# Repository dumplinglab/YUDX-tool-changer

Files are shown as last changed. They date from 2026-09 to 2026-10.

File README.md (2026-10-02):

# YUDX Tool Changer

An open-source automatic tool-changing system for 3D printers that enables **1-second tool changes with almost zero waste**.

## ✨ Key Features

- **~1 second tool change** — near-instant switching between tool heads, and dramatically reducing purge/waste material compared to traditional multi-material setups.
- **Preheatable tool heads** — each tool head has its own independent heater and thermistor, so it can be pre-heated in advance while parked.
- **Simple, reliable mechanism** — the tool-docking mechanism is based on a one-way bearing design, which keeps the system mechanically simple while remaining stable and reliable.

## 🖨️ Compatibility

Currently designed as a conversion for:
- **Voron 2.4**
- **Voron Trident**

Support for additional printer platforms may be added in the future.

## 👤 Author

It's just me — **dumpling**. No company, no team, just one person working on this.

I'm a student in Shanghai, just starting my third year of university, and I've loved DIY 3D printers since middle school, designing and building my own machines for years.

Since this is a one-person project that I work on in my spare time, updates may come slowly — thanks for your patience and interest!

## 🧵 Firmware & G-code

The G-code provided in this repository is generated for **RepRapFirmware (RRF)**.

If you are running **Klipper**, you will need to write your own tool-change macros/G-code for now. If you do write a working Klipper configuration, contributions are very welcome — please consider opening a pull request so other Klipper users can benefit.

## 💬 Community

Join the Discord: [https://discord.gg/huHw8kzNXp](https://discord.gg/huHw8kzNXp)

## 🔧 Installation

See [Assembly Instructions](<./YUDX Assembly Instruction.pdf>) for the full build and installation guide.

## 📦 Bill of Materials

See [BOM.xlsx](<./"YUDX"BOM.xlsx>) for the complete parts list.

## 📄 License

See the [LICENSE](./LICENSE) file for details.

## 📖 Project Background

I've been developing an automatic tool-changing 3D printer since 2024. Initially, I experimented with a design similar to the Prusa XL's tool-changing approach.

Everything changed in April 2025, when I saw the reveal video for Bondtech's INDX system. I was blown away, and it pushed me to take the design in a new direction. Many thanks to Bondtech for the inspiration.

I explored a number of different mechanical designs. Then, one night in May 2025, the idea for the current one-way bearing mechanism came to me in a dream — a solution that turned out to be simple, stable, and reliable. Since building and machining the first prototype, the design has gone through continuous refinement, and reliability is now solid.

## 🙏 Acknowledgments

- **Bondtech** — for the INDX system, which was a huge inspiration for the tool-changing approach used in this project.
- **whyme12** — for helping add screws and nuts, and for completing the BOM spreadsheet.
- **Voron Design** — the open-source Voron project that this system is built on top of.
- **RepRapFirmware (RRF)** — the open-source firmware this project's G-code is developed for.

## 🤝 Contributing

Contributions are welcome, especially:
- Klipper-compatible tool-change G-code / macros
- Bug reports and reliability improvements
- Documentation improvements

Feel free to open an issue or pull request.

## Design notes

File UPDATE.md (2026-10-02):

# \## 🔴 Important Changes

# 1\. \*\*Corrected the Maxwell locating point structure\*\*

# For the original structure: under high-flow conditions, the locating point would slip, directly affecting print accuracy. It has now been adjusted so that \*\*the greater the extrusion amount, the tighter the clamping\*\*. Even if the extruder skips steps, the toolhead will not slip, greatly improving positioning reliability.

# 2\. \*\*Replaced square nuts with heat-set inserts\*\*

# The original solution used square nuts, which tended to loosen after long-term use; they have been changed to heat-set inserts to improve the long-term stability.

# 

# \## 🟡 Minor Optimizations and Detail Adjustments

# 1\. Shifted the push latch switch upward by 3 mm to prevent interference/collision with screws when removing or installing the toolhead.

# 2\. Adjusted the silicone plug installation position to correct the off-center issue and ensure it is centered.

# 3\. Added a lightweight structural design to CNC machined parts to reduce weight while maintaining strength.

# 4\. Changed multiple self-tapping screw mounting positions to heat-set inserts to improve connection durability.

# 5\. Fully added the screw standard parts in the assembly file.

# 6\. Fixed several minor design flaws.

\## 🟢 Pending Updates

1\. The BOM and assembly instructions have not been updated yet; I will update them later when I have time.

2\. The new version has overridden the previous whyme12 version's design of "using a Hall switch to detect whether the toolhead change is successful." Later, I plan to create a new branch to add this design back.

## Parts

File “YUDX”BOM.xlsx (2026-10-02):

 | Info: 1. The finished YUDX extruder kit may be released in the coming months. You may wait for its launch. 2. Amazon links were found by Claude Code. Links may be incorrect, please feedback any errors to me. 3. discord:https://discord.gg/huHw8kzNXp 4. https://github.com/dumplinglab/YUDX-tool-changer
number | Notes | Part Name (corresponds to STEP file) | Qty | Type | Amazon Product | Price | Amazon Link
1 | VORON existing part | MGN12H_block | 1 | Standard Part | MGN12H 300mm Premium Linear Guide Rail 2 Pcs MGN12 Linear Slide 8mm for 3D Printer CNC (2 Pcs/Pack) | $26.92 | https://www.amazon.com/dp/B09ZPHPB5F
2 | VORON existing part | MGN12 | 1 | Standard Part | MGN12H 300mm Premium Linear Guide Rail 2 Pcs MGN12 Linear Slide 8mm for 3D Printer CNC (2 Pcs/Pack) | $26.92 | https://www.amazon.com/dp/B09ZPHPB5F
3 | VORON existing part | Aluminum profiles | 1 | Standard Part |  | $0
4 | Extruder kit | outer_shell_of_extruder | 1 | 3D Printed Part |  | $0
5 | Extruder kit | gear_container_plastic_part | 2 | 3D Printed Part |  | $0
6 | Extruder kit | rack_below_part | 1 | 3D Printed Part |  | $0
7 | Extruder kit | double_layer_gear | 2 | Custom Gear |  | $35
8 | Extruder kit | extrude_gear | 2 | Custom Gear |  | $19.40
9 | Extruder kit | 0.5m10gear | 2 | Custom Gear |  | $32
10 | Extruder kit | gear_container_metal_part | 2 | Custom CNC Part |  | $18.8
11 | Extruder kit | axle_for_extrude_gear | 2 | Custom CNC Part |  | $23
12 | Extruder kit | gear_container_metal_part_mirror | 2 | Custom CNC Part |  | $18.8
13 | Extruder kit | extruder_bottom_metal_part | 1 | Custom CNC Part |  | $9.9
14 | Extruder kit | extruder_top_metal_part | 1 | Custom CNC Part |  | $9.9
15 | Extruder kit | extruder_top_metal_part_mirror | 1 | Custom CNC Part |  | $9.9
16 | Extruder kit | line_cut_rack | 1 | Custom Wire-cut Part |  | $24
17 | Extruder kit | 36_stepper_motor | 1 | Custom Motor |  | $12.82
18 | Extruder kit | screwM3_14 | 2 | Screw |  | $0.50
19 | Extruder kit | one_way_bearing | 2 | Custom Bearing |  | $7.47
20 | Extruder kit | extrude_wheel | 2 | Standard Part | Precise Double Drived Gear Extruder Gear Set for HGX-LITE-extruder Hardened Steel Extruder Driver Gear Set | $10.42 | https://www.amazon.com/gp/product/B0FD3XDJMK
21 | Extruder kit | needle_bearing | 2 | Standard Part | Precise Double Drived Gear Extruder Gear Set for HGX-LITE-extruder Hardened Steel Extruder Driver Gear Set | $0 | https://www.amazon.com/gp/product/B0FD3XDJMK
22 | Extruder kit | 4mm_flange_bearing | 6 | Standard Part | M METERXITY 20pcs MF63ZZ Flange Ball Bearings, 3mm x 6mm x 2.5mm, Dual Metal Seal Chrome Steel (GCr15) | $7.10 | https://www.amazon.com/dp/B0F4XS52R6
23 | Extruder kit | 3mm_flange_bearing | 4 | Standard Part | M METERXITY 20pcs MF63ZZ Flange Ball Bearings, 3mm x 6mm x 2.5mm, Dual Metal Seal Chrome Steel (GCr15) | $7.10 | https://www.amazon.com/dp/B0F4XS52R6
24 | Extruder kit | 4mm_axle | 2 | Standard Part |  | $0.5
25 | Extruder kit | cylinder_pin1.5_5 | 6 | Standard Part | Swpeet 300Pcs 15 Sizes M1 M1.5 304 Stainless Steel Dowel Pin Assortment Kit | $6.72 | https://www.amazon.com/dp/B0G8ZXBGN1
26 | Extruder kit | 4mm_flange_bearing_8mm | 2 | Standard Part | F693ZZ Flange Ball Bearing, ID 3mm x OD 8mm x Width 4mm, Double Metal Shield Deep Groove, Pre-lubricated (GCr15) 10 Pcs | $5.98 | https://www.amazon.com/dp/B0CRLH1WT1
27 | Extruder kit | spring_0.8x7x30 | 1 | Standard Part |  | $2
28 | Extruder kit | 4mm_ball | 32 | Standard Part | 50pcs 4mm 304 Stainless Steel Bearing Balls, 0.15in G200 Precision 28HRC | $4.11 | https://www.amazon.com/dp/B0F2S945ZC
29 | Extruder kit | square_nut | 2 | Standard Part | M3nS Prusa Thin M3 Square Nuts - A2 Stainless Steel DIN 562 (Qty 25) | $5.95 | https://www.amazon.com/dp/B0BD2N9KTV
30 | Extruder kit | mini_door_lock_switch | 16 | Standard Part | 5PCS Door Lock Switch PR-03 Key Switches | $24.68 | https://www.amazon.com/5PCS-Door-Switch-PR-03-Switches/dp/B0H9KGYYP8
31 | Extruder kit | 4.5mm_silicon_sleeve | 7 | Standard Part |  | $5.2
32 |  | Tool_head_front_part | 1 | 3D Printed Part |  | $0
33 |  | Tool_head_back_part | 1 | 3D Printed Part |  | $0
34 |  | voron_connecting_part | 1 | 3D Printed Part |  | $0
35 |  | throat_cooling_fan_seat | 1 | 3D Printed Part |  | $0
36 |  | model_cooling_fan_seat | 1 | 3D Printed Part |  | $0
37 |  | front_cover | 1 | 3D Printed Part |  | $0
38 |  | back_cover | 1 | 3D Printed Part |  | $0
39 |  | tool_head_seat | 7 | 3D Printed Part |  | $0
40 |  | nozzle_cleaning_part | 7 | 3D Printed Part |  | $0
41 |  | air_guide | 7 | 3D Printed Part |  | $0
42 |  | magnet_5-15-3 | 32 | Standard Part | BEST CHOICE Neodymium Magnets 15x3mm, 50pcs Fridge Magnets Rare Earth Magnets for Crafts | $11.21 | https://www.amazon.com/Neodymium-Rectangular-Industrial-Applications-15mmx5mmx4mm/dp/B0GKPBWNSF
43 |  | Bambu_Hotend | 8 | Standard Part | Genuine Bambu Lab Hotend with Nozzle for P1S P1P X1C X1 Carbon 3D Printer .4mm Hardened Steel | $160 | https://www.amazon.com/Genuine-Printer-4mm-Hardened-Steel/dp/B0D2WG7CXQ
44 |  | 2510fan | 1 | Standard Part | 2510 Axial Fan DC 24V, 25x25x10mm Dual Ball Bearing Low Noise Brushless Cooling Fan for 3D Printer Extruder Hotend (2 Pcs) | $11.20 | https://www.amazon.com/dp/B0FR99DQWY
45 |  | 5020fan | 1 | Standard Part | Cooling Case PC Fan 50x50x20mm DC 24V 0.15A 5020 Brushless 2-Pin XH2.54 5500RPM | $4.68 | https://www.amazon.com/dp/B0CWCXGYG1
46 |  | bed_switch | 1 | Standard Part | 20PCS Micro Limit Switch NO+NC Hinge Straight Lever 3PIN 125V 1A Mouse Micro Touch Button Momentary Switch Black | $4.89 | https://www.amazon.com/DAOKAI-Switch-Straight-Button-Momentary/dp/B09WVMRD5V
47 |  | 3010fan | 8 | Standard Part | 3010 Axial Fan DC 24V, 30x30x10mm Hydraulic Bearing Low Noise Silent Brushless Cooling Fan for 3D Printer Extruder Hotend (2 Pcs) | $10.46 | https://www.amazon.com/dp/B0FRFNZFDP

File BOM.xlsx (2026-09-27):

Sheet: BOM
 | Info: 1. The finished YUDX extruder kit may be released in the coming months. You may wait for its launch. 2. Amazon links were found by Claude Code. Links may be incorrect, please feedback any errors to me. 3. discord:https://discord.gg/vE4ExaVR3 4. https://github.com/dumplinglab/YUDX-tool-changer
number | Part group | Part Name (corresponds to STEP file) | Qty | Type | Details | Notes
1 | VORON existing part | MGN12H_block | 1 | Standard Part | MGN12H 300mm Premium Linear Guide Rail 2 Pcs MGN12 Linear Slide 8mm for 3D Printer CNC (2 Pcs/Pack)
2 | VORON existing part | MGN12 | 1 | Standard Part | MGN12H 300mm Premium Linear Guide Rail 2 Pcs MGN12 Linear Slide 8mm for 3D Printer CNC (2 Pcs/Pack)
3 | VORON existing part | Aluminum profiles | 1 | Standard Part
4 | Printer specific part | voron_connecting_part | 1 | 3D Printed Part |  | Add mounting option for EBB36?
5 | Printer specific part | M3x8mm ISO4762 | 4 | Standard Part | Screws to mount to MGN12 block
6 | Extruder | outer_shell_of_extruder | 1 | 3D Printed Part
7 | Extruder | double_layer_gear | 2 | Custom Gear
8 | Extruder | extrude_gear | 2 | Custom Gear
9 | Extruder | extrude_wheel | 2 | HGX-Lite | All included in a single HGX-Lite gear kit
10 | Extruder | needle_bearing | 2 | HGX-Lite | All included in a single HGX-Lite gear kit
11 | Extruder | one_way_bearing | 2 | Standard Part | HF0306
12 | Extruder | gear_container_metal_part | 2 | CNC
13 | Extruder | axle_for_extrude_gear | 2 | Custom part? | Diameter: 3mm, length: 24mm, 8mm ground flat on one side (1/4 D-Shaft) | change to D-shaft?
14 | Extruder | 0.5m10gear | 2 | Standard Part? | M0.5, 10 teeth, 3mm D-shaft | change to 12 teeth for more strength?
15 | Extruder | gear_container_plastic_part | 2 | 3D Printed Part
16 | Extruder | gear_container_metal_part_mirror | 2 | CNC
17 | Extruder | 4mm_flange_bearing | 6 | Standard Part | MF74ZZ flange bearing 4mmx7mmx2.5mm
18 | Extruder | 3mm_flange_bearing | 4 | Standard Part | MF63ZZ flange bearing 3mmx6mmx2.5mm
19 | Extruder | 4mm_axle | 2 | Standard Part | length 32mm
20 | Extruder | line_cut_rack | 1 | Custom Wire-cut Part | M0.5 gears require wire cutting
21 | Extruder | rack_below_part | 1 | CNC
22 | Extruder | extruder_bottom_metal_part | 1 | CNC
23 | Extruder | 36_stepper_motor | 1 | Standard part? | possibly fitting motor: Flashforge AD5X extruder motor
24 | Extruder | cylinder_pin1.5_5 | 6 | Standard Part | Diameter: 1.5mm, Length: 4mm
25 | Extruder | 4mm_flange_bearing_8mm | 2 | Standard Part | MF84ZZ flange bearing 4mmx8mmx3mm
26 | Extruder | extruder_top_metal_part_mirror | 1 | CNC
27 | Extruder | extruder_top_metal_part | 1 | CNC
28 | Extruder | throat_cooling_fan_seat | 1 | 3D Printed Part
29 | Extruder | 2510fan | 1 | Standard Part
30 | Extruder | model_cooling_fan_seat | 1 | 3D Printed Part
31 | Extruder | spring_0.8x7x30mm | 1 | Standard Part
32 | Extruder | 5020fan | 1 | Standard Part
33 | Extruder | bed_switch | 1 | Standard Part | for example: Omron D2F-01
34 | Extruder | M2x8mm ISO4762 | 2 | Standard Part | M2x8mm ISO4762
35 | Extruder | M3x10mm ISO7380-1 | 4 | Standard Part | Screws to mount model_cooling_fan_seat
36 | Extruder | front_cover | 1 | 3D Printed Part
37 | Extruder | M3x8mm ISO7380-1 | 2 | Standard Part | Screws to mount front_cover
38 | Extruder | back_cover | 1 | 3D Printed Part
39 | Extruder | M3x30mm ISO7380-1 | 8 | Standard Part | Screws to mount extruder_top_metal_part to extruder_bottom_metal_part
40 | Extruder | M3x8mm ISO10642 | 2 | Standard Part | Screws to mount stepper motor
41 | Extruder | M3x10mm ISO4762 | 4 | Standard Part | Screws to mount extruder_bottom_metal_part to voron_connecting_part
42 | Extruder | M3x8mm ISO10642 | 4 | Standard Part | Screws to mount gear_container_metal_part
43 | Extruder | M3x5mm ISO7380-1 | 2 | Standard Part | Screws to mount gear_container_plastic_part to gear_container_metal_part
44 | Extruder | M3x12mm ISO7380-1 | 2 | Standard Part | Screws for Spring
45 | Extruder | M3x14mm ISO7380-1 | 4 | Standard Part | Screws to mount 2510fan | Walls could be too thin around heat inserts, needs to be tested
46 | Extruder | M3x12mm ISO7380-1 | 3 | Standard Part | Screws to mount throat_cooling_fan_seat
47 | Extruder | A1104_hall_effect_sensor | 1 | Standard Part | (optional) Hall effect sensor A1104LUA-T (not SMD variant) to detect tool change fails
48 | Extruder & Toolhead | magnet_5-15-3 | 4 + N*4 | Standard Part |  | Pocket size in Step maybe to small? Only 14.5x4.5mm
49 | Toolhead | Tool_head_front_part | N | 3D Printed Part |  | Pocket size in Step maybe to small? Only 14.5x4.5mm
50 | Toolhead | Bambu_Hotend | N | Standard Part |  | Create second Tool_head_front_part to support Snapmaker U1 hotends
51 | Toolhead | 4mm_ball | N*4 | Standard Part | 4mm ball bearing ball
52 | Toolhead | Tool_head_back_part | N | 3D Printed Part |  | Do the latches work when 3d printed and not break off?
53 | Toolhead | square_nut | N*2 | Standard Part
54 | Toolhead | M3x14mm ISO4762 | N*2 | Standard Part | Screws to mount Bambu_Hotend
55 | Toolhead | M3x6mm ISO7380-1 | N*4 | Standard Part | Screws to mount Tool_head_back_part to Tool_head_front_part
56 | Toolhead | Magnet_4x2mm | N | Standard Part | Diameter 4mm, height 2mm | To be able to detect toolchange success using hall effect sensor
57 | Dock | tool_head_seat | N | 3D Printed Part |  | Maybe add additional screws from front?
58 | Dock | mini_door_lock_switch | N*2 | Standard Part
59 | Dock | nozzle_cleaning_part | N | 3D Printed Part
60 | Dock | 3010fan | N | Standard Part
61 | Dock | air_guide | N | 3D Printed Part
62 | Dock | 4.5mm_silicon_sleeve | N | ??? |  | where to get this part from?
63 | Dock | M3x12mm ISO4762 | N*4 | Standard Part | Screws to mount nozzle_cleaning_part
64 | Dock | M3x20mm ISO4762 | N*4 | Standard Part | Screws to mount 3010fan and air_guide
65 | Dock | M3x8mm ISO4762 | N*2 | Standard Part | Screws to mount tool_head_seat to aluminium extrusion
66 | Dock | T-nut | N*2 | Standard Part | T-nut to mount tool_head_seat to aluminium extrusion
67 | Overall | Heat set inserts | 31+N*8 | Standard Part | Heat set inserts M3x5x4mm (Voron style)

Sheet: Screw types
Type | Quantity
M3x8mm ISO4762 | 4+N*2
M3x10mm ISO4762 | 4
M3x12mm ISO4762 | N*4
M3x14mm ISO4762 | N*2
M3x20mm ISO4762 | N*4
M3x8mm ISO10642 | 6
M3x5mm ISO7380-1 | 2
M3x6mm ISO7380-1 | N*4
M3x8mm ISO7380-1 | 2
M3x10mm ISO7380-1 | 4
M3x12mm ISO7380-1 | 5
M3x14mm ISO7380-1 | 4
M3x30mm ISO7380-1 | 8

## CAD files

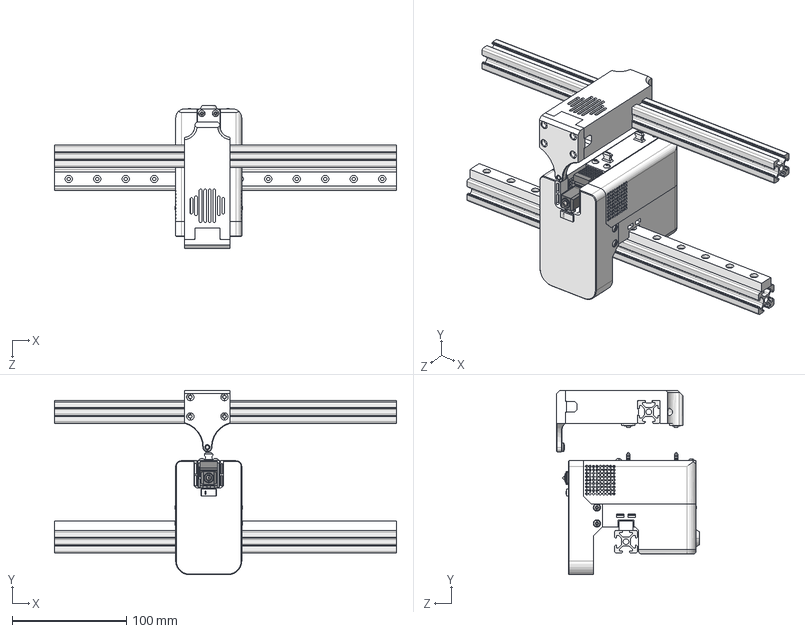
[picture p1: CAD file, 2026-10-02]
CAD/YUDX_assemble.STEP
300.0 x 161.8 x 125.5 mm
outer_shell_of_extruder
extrude_gear
extrude_wheel
needle_bearing
one_way_bearing
gear_container_metal_part
axle_for_extrude_gear
0.5m10gear
gear_container_plastic_part
gear_container_metal_part_mirror
4mm_flange_bearing x 2
3mm_flange_bearing x 2
4mm_axle
DIN_7991_M3x8 x 2
double_layer_gear x 2
line_cut_rack
rack_below_part
36_stepper_motor
4mm_flange_bearing_8mm x 4
extruder_top_metal_part_rev3
cylinder_pin1.5_5 x 6
magnet_5-15-3 x 8
Mirror_extruder_top_metal_part_rev3
M3_30 x 8
extruder_bottom_metal_part_CNC
Mirror_extrude_gear
Mirror_extrude_wheel
Mirror_needle_bearing
Mirror_one_way_bearing
Mirror_gear_container_metal_part
Mirror_axle_for_extrude_gear
Mirror_0.5m10gear
Mirror_gear_container_plastic_part
Mirror_gear_container_metal_part_mirror
Mirror_4mm_flange_bearing x 2
Mirror_3mm_flange_bearing x 2
Mirror_4mm_axle
Mirror_DIN_7991_M3x8 x 2
Tool_head_front_part
heat_sink_fin_Bambu
nozzle_and_throat_Bambu
P1P_ceramic_heater
silicone_sleeve
4mm_ball x 4
Tool_head_back_part
screwM3_14 x 2
M3_heatset_nut x 19
M3_heatset_nut_small x 4
M3_6 x 4
voron_connecting_part
throat_cooling_fan_seat
2510fan
ISO_4762_M3x10 x 7
ISO_7380_M3x14 x 4
model_cooling_fan_seat
5020fan
bed_switch
M3_10 x 4
DIN_912_M2x8 x 2
MGN12H_block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

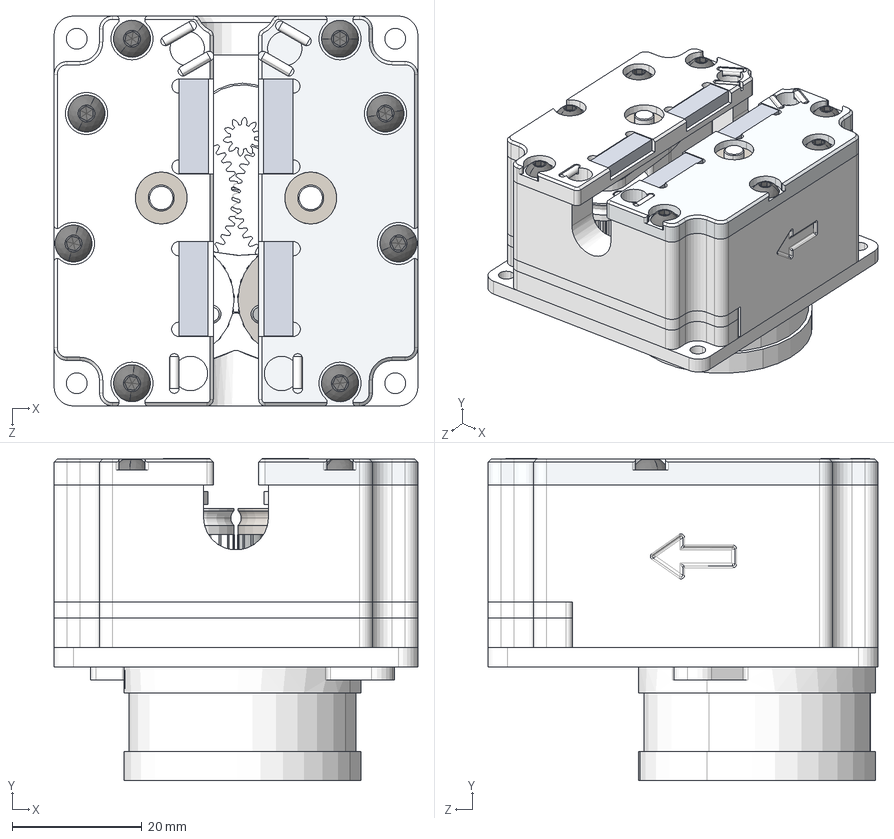
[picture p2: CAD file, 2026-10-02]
CAD/YUDX_Extruder.STEP
56.0 x 49.6 x 60.0 mm
outer_shell_of_extruder
extrude_gear
extrude_wheel
needle_bearing
one_way_bearing
gear_container_metal_part
axle_for_extrude_gear
0.5m10gear
gear_container_plastic_part
gear_container_metal_part_mirror
4mm_flange_bearing x 2
3mm_flange_bearing x 2
4mm_axle
DIN_7991_M3x8 x 2
double_layer_gear x 2
line_cut_rack
rack_below_part
36_stepper_motor
4mm_flange_bearing_8mm x 4
extruder_top_metal_part_rev3
cylinder_pin1.5_5 x 6
magnet_5-15-3 x 4
Mirror_extruder_top_metal_part_rev3
M3_30 x 8
extruder_bottom_metal_part_CNC
Mirror_extrude_gear
Mirror_extrude_wheel
Mirror_needle_bearing
Mirror_one_way_bearing
Mirror_gear_container_metal_part
Mirror_axle_for_extrude_gear
Mirror_0.5m10gear
Mirror_gear_container_plastic_part
Mirror_gear_container_metal_part_mirror
Mirror_4mm_flange_bearing x 2
Mirror_3mm_flange_bearing x 2
Mirror_4mm_axle
Mirror_DIN_7991_M3x8 x 2

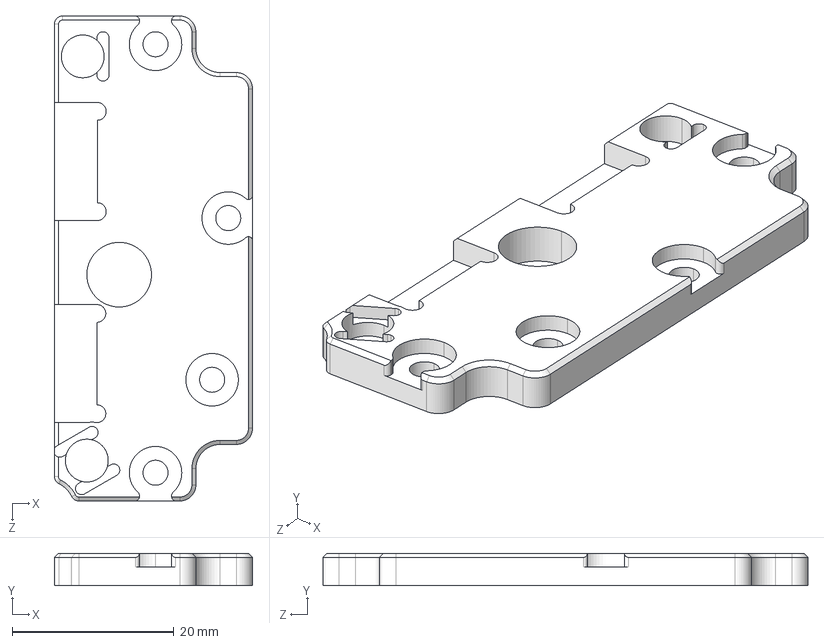
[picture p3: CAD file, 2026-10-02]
CNC Parts/extruder_top_metal_part_mirror.step
24.5 x 4.00 x 60.0 mm

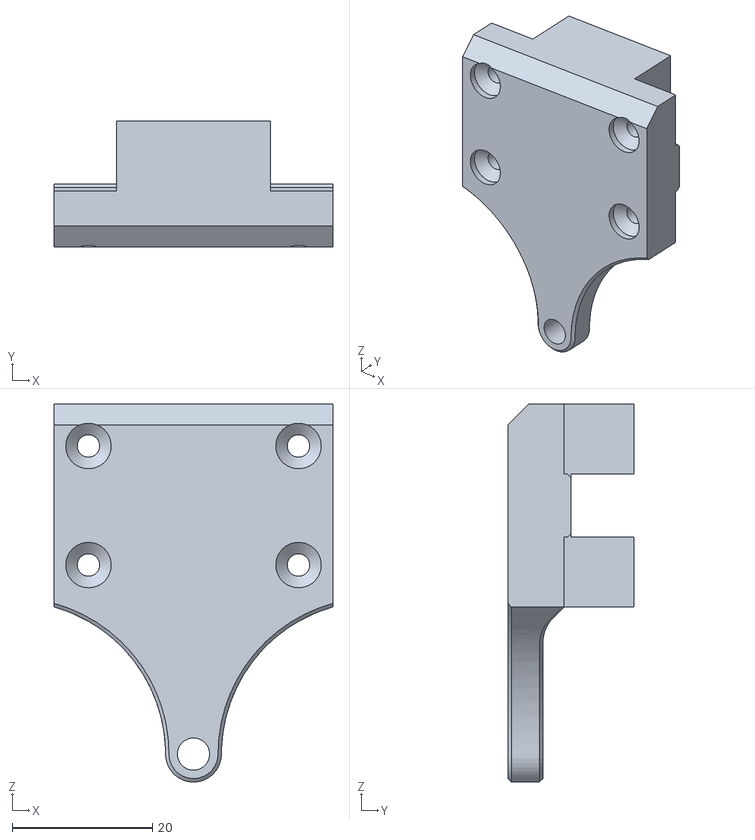
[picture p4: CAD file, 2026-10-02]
STLs/Dock/nozzle_cleaning_part.stl
39.8 x 18.0 x 54.0

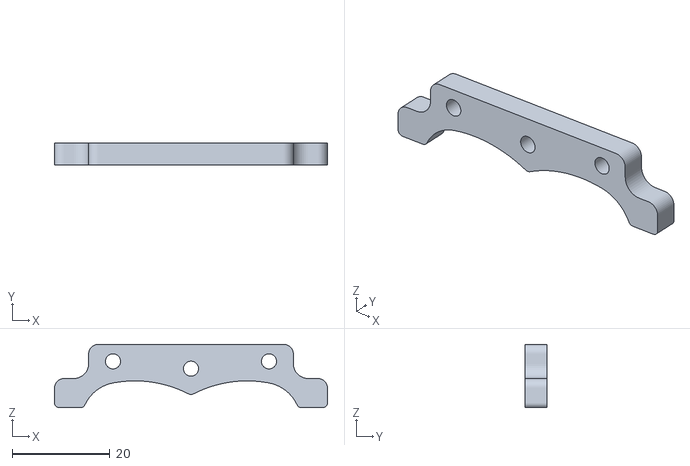
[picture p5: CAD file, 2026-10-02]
STLs/Extruder/rack_below_part.STL
56.0 x 4.50 x 13.0

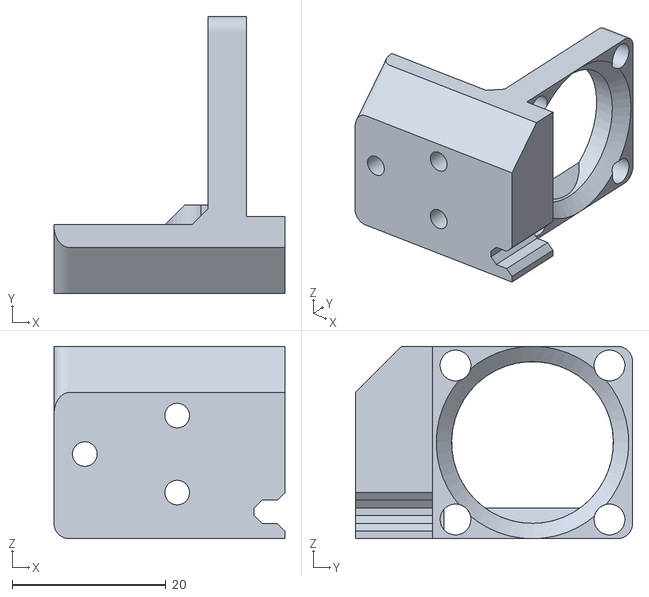
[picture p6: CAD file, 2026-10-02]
STLs/Printer specific/Voron2.4 MGN12/throat_cooling_fan_seat.stl
30.0 x 36.0 x 25.0

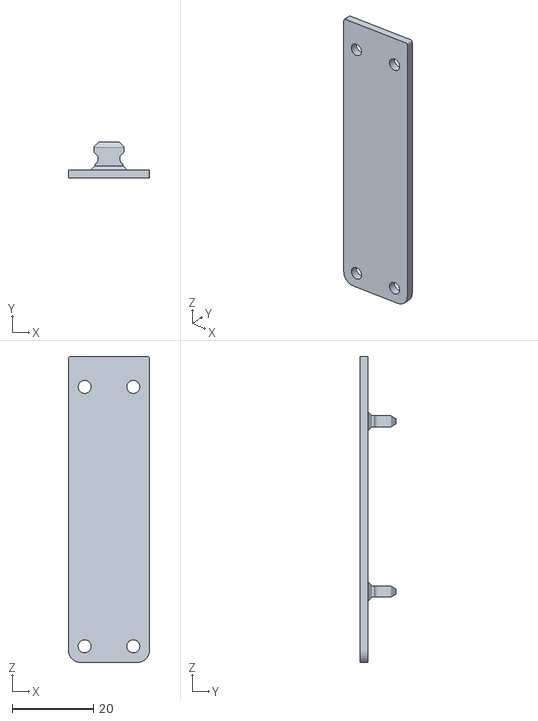
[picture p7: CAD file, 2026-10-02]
STLs/Toolhead/Tool_head_back_part.stl
20.0 x 9.00 x 75.5

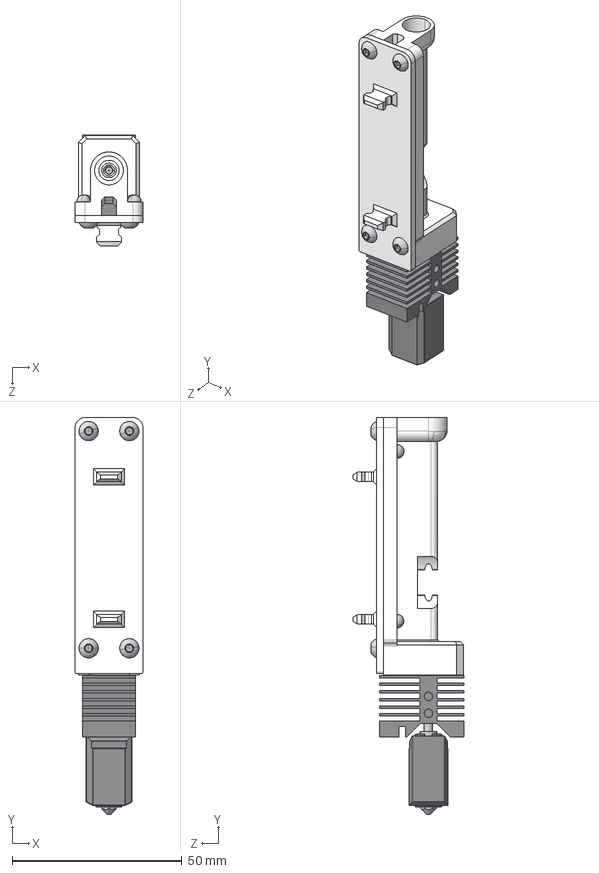
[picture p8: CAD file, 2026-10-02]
CAD/Tool_head_assumption.STEP
20.0 x 117.0 x 32.8 mm
Tool_head_front_part
heat_sink_fin_Bambu
nozzle_and_throat_Bambu
P1P_ceramic_heater
silicone_sleeve
4mm_ball x 4
Tool_head_back_part
magnet_5-15-3 x 4
screwM3_14 x 2
M3_heatset_nut x 2
M3_heatset_nut_small x 4
M3_6 x 4

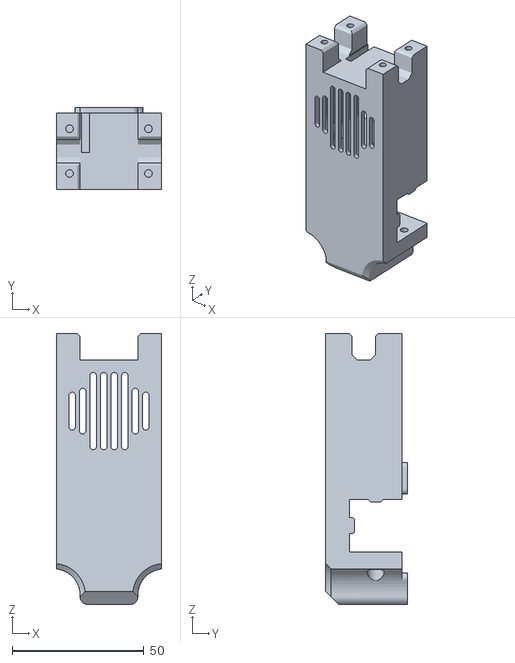
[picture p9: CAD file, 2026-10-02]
STLs/Dock/tool_head_seat.stl
39.8 x 31.0 x 103.0

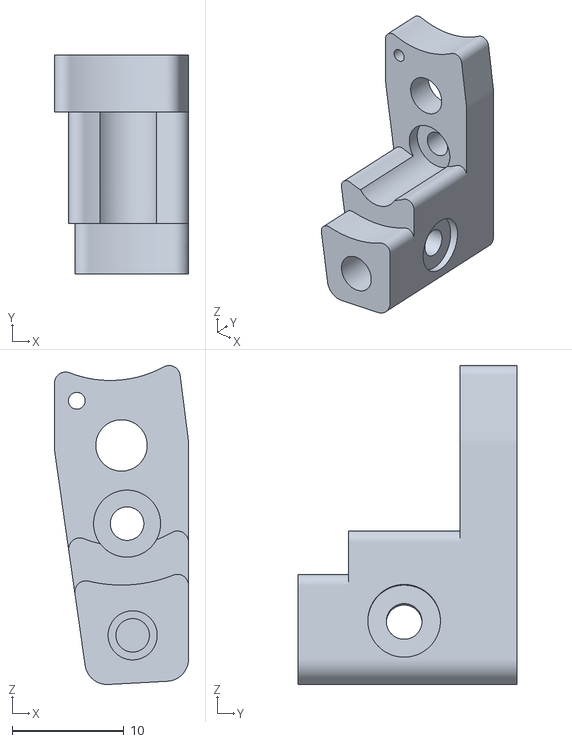
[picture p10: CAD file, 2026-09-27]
STLs/Extruder/gear_container_plastic_part.stl
12.0 x 19.6 x 28.6

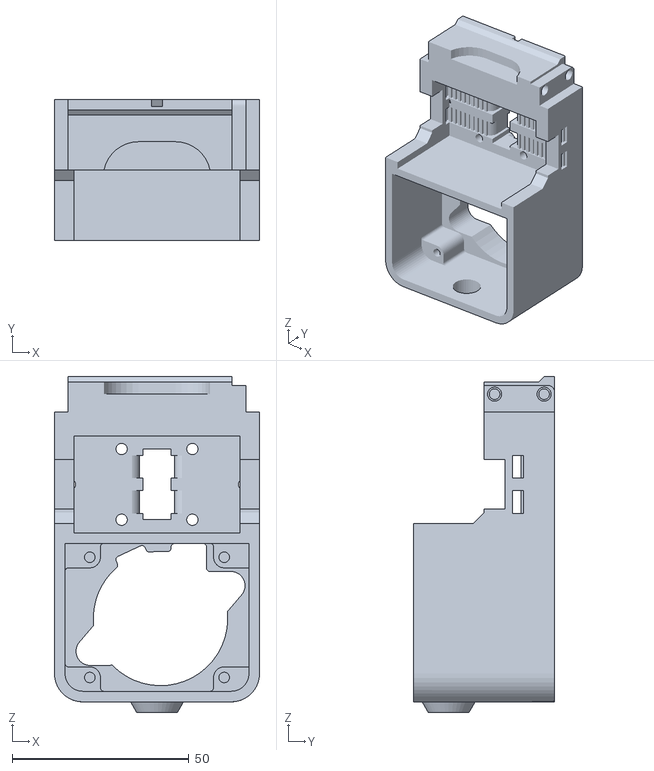
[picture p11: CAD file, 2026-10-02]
STLs/Printer specific/Voron2.4 MGN12/voron_connecting_part.stl
58.0 x 40.0 x 95.0

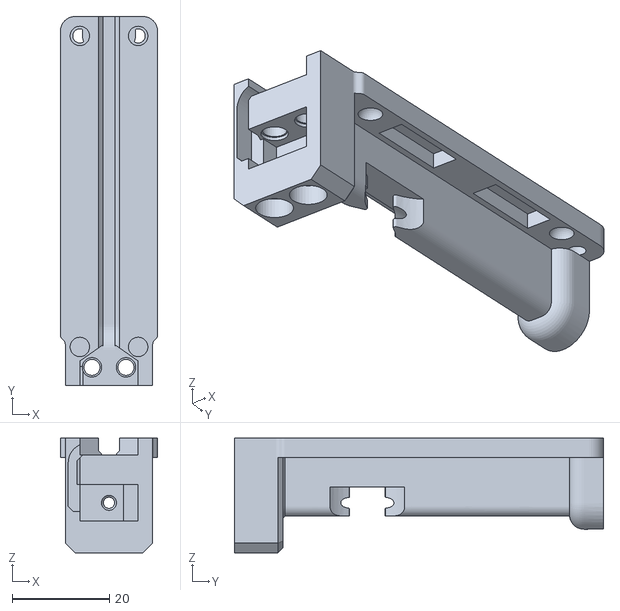
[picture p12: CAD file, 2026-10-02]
STLs/Toolhead/Tool_head_front_part(printed_vertically).STL
20.0 x 75.9 x 23.6

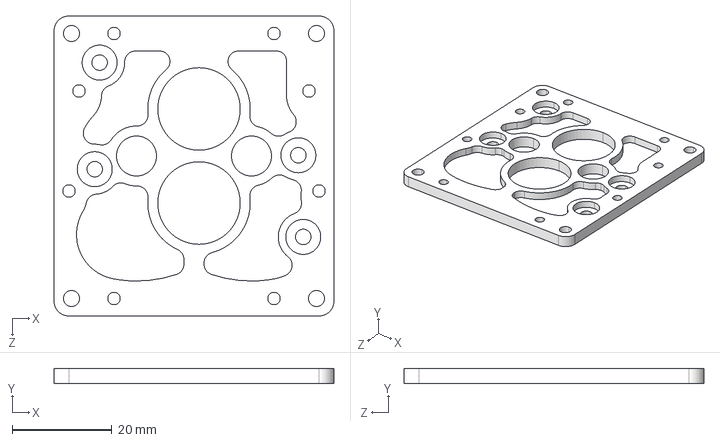
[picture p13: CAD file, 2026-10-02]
CNC Parts/extruder_bottom_metal_part(Lightweight).STEP
56.0 x 3.00 x 60.0 mm

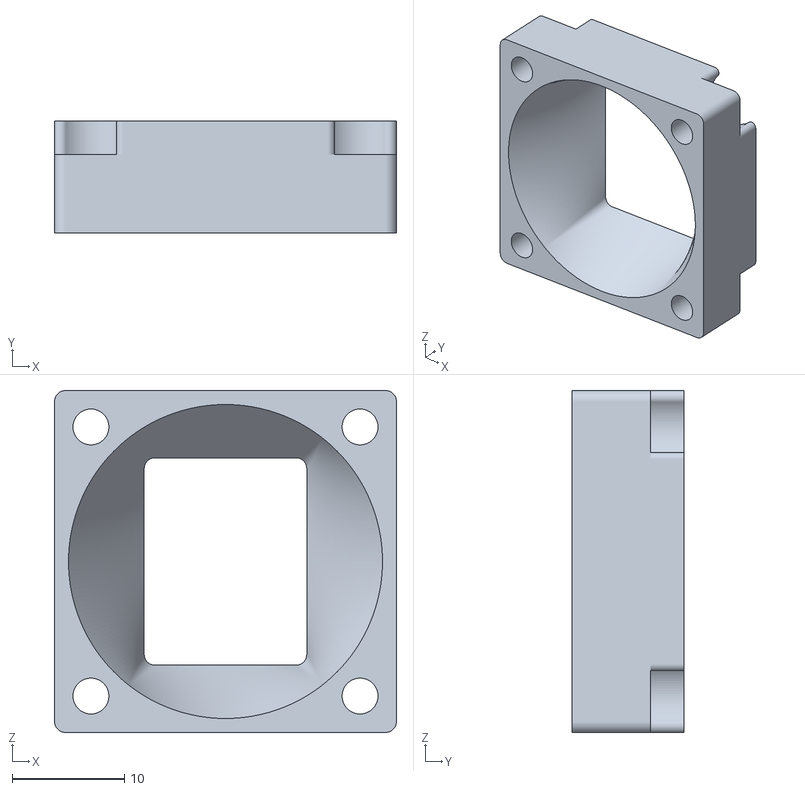
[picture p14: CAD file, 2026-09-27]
STLs/Dock/air_guide.stl
30.5 x 10.0 x 30.5

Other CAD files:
CNC Parts/extruder_top_metal_part.step
STLs/Extruder/gear_container_plastic_part_mirrored.stl
STLs/Printer specific/Voron2.4 MGN12/model_cooling_fan_seat.stl
CNC Parts/2x_gear_container_metal_part.step
CNC Parts/2x_gear_container_metal_part_mirror.step
CNC Parts/extruder_bottom_metal_part(standard).step
CNC Parts/line_cut_rack.step
STLs/Extruder/outer_shell_of_extruder.stl
STLs/Printer specific/Voron2.4 MGN12/back_cover.stl
STLs/Printer specific/Voron2.4 MGN12/front_cover.stl

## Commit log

2026-10-02 new version 2026.10
    ## 🔴 Important Changes
    1. **Corrected the Maxwell locating point structure**
    For the original structure: under high-flow conditions, the locating point would slip, directly affecting print accuracy. It has now been adjusted so that **the greater the extrusion amount, the tighter the clamping**. Even if the extruder skips steps, the toolhead will not slip, greatly improving positioning reliability.
    2. **Replaced square nuts with heat-set inserts**
    The original solution used square nuts, which tended to loosen after long-term use; they have been changed to heat-set inserts to improve the long-term stability.
    ## 🟡 Minor Optimizations and Detail Adjustments
    1. Shifted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
    [2x_double_layer_gear.step, 2x_extrude_gear.step, Tool_head_assumption.STEP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]
2026-10-25 Added parts library, part IDs, renamed parts and updated BOM
2026-10-25 First release of Klipper macros and configuration
2026-10-25 Added PARK_TOOL macro to Gcode/Klipper/macros.cfg
